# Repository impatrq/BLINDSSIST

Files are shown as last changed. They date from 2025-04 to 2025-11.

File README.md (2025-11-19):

<h1 align="center"><u>BLINDASSIST</u></h1>

<p align="center">
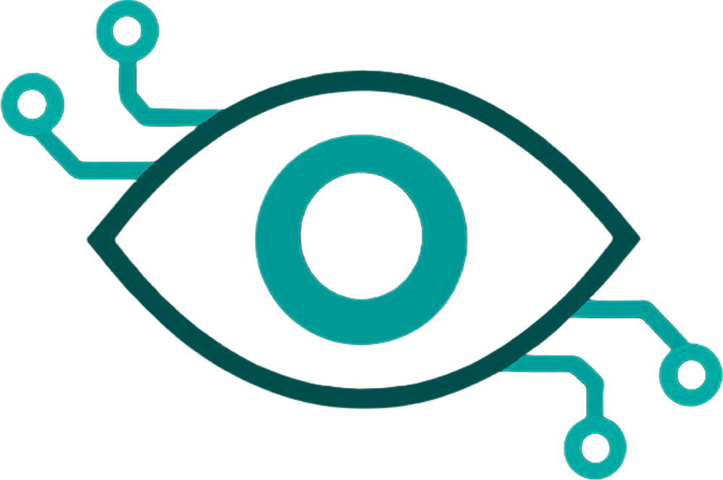
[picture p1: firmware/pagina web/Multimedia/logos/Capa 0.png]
BLINDSSIST Logo
  
</p>

<p align="center">

<!-- Video de Presentación -->
<a href="ACA_PONES_EL_LINK_DE_YOUTUBE_O_DRIVE" target="_blank">
  
</a>
<br>

<!-- Instagram -->
<a href="https://www.instagram.com/blindassist/" target="_blank">
  
</a>

<!-- LinkedIn -->
<a href="https://www.linkedin.com/in/proyecto-blindassist-72b0a7396" target="_blank">
  
</a>

<!-- Página Web -->
<a href="https://castiilloramiro.github.io/BlindWeb/" target="_blank">
  
</a>

<!-- Gmail -->
<a href="https://mail.google.com/mail/?view=cm&to=blindassist2025@gmail.com" target="_blank">
  
</a>

<!-- Linktree -->
<a href="http://linktr.ee/blindassist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" target="_blank">
  
</a>

</p>
## 🎯 Descripción  

BLINDASSIST es un proyecto orientado a facilitar el tránsito de usuarios con discapacidad visual en su vida cotidiana. A través de un dispositivo colgante —o integrado en algún accesorio— funciona como ayuda al bastón tradicional, ofreciendo:  

- 🔍 **Detección por cámara** de elementos específicos (por ejemplo: cestos de basura, señalizaciones, etc.).  

- 📡 **Sensores láser de proximidad** para obstáculos (ramas, postes, etc.).  

- 🔊 **Alertas sensoriales** (audio + vibración) para que el usuario pueda evitar los obstáculos.  

El dispositivo es portátil, compacto, fácil de llevar y diseñado para no interferir en las actividades diarias del usuario.

---

## 👥 Público objetivo  

- 👨‍🦯 Personas con discapacidad visual o movilidad reducida.  

- 🏥 Instituciones, aseguradoras o centros de rehabilitación que buscan tecnologías de apoyo.  

- 👨‍👩‍👧 Familiares o cuidadores que desean aumentar la seguridad en el tránsito.  

---

## 🛠️ Tecnologías

- **Hardware**: Sensores láser, cámara, actuadores de vibración
- **Firmware**: Código embebido para microcontroladores
- **Procesamiento**: Visión por computadora, detección de objetos
- **Frontend**: Interfaz web para configuración y monitoreo

---

## 📂 Estructura del repositorio  

```
BLINDSSIST/
├── Hardware/          # Diseño y esquemáticos del dispositivo
├── firmware/          # Código embebido y firmware
├── docs/              # Documentación del proyecto
```

---

## 🚀 Funcionalidades

| Característica | Descripción |
|---|---|
| 🎥 **Visión por IA** | Detección automática de elementos del entorno |
| 📏 **Sensores de Proximidad** | Detección de obstáculos en tiempo real |
| 🔊 **Feedback Auditivo** | Alertas de audio contextuales |
| 📳 **Feedback Háptico** | Vibraciones para notificaciones táctiles |
| 💻 **Interfaz Web** | Configuración y monitoreo del dispositivo |

---

## 🧑‍💻 Equipo 

<p align="center">
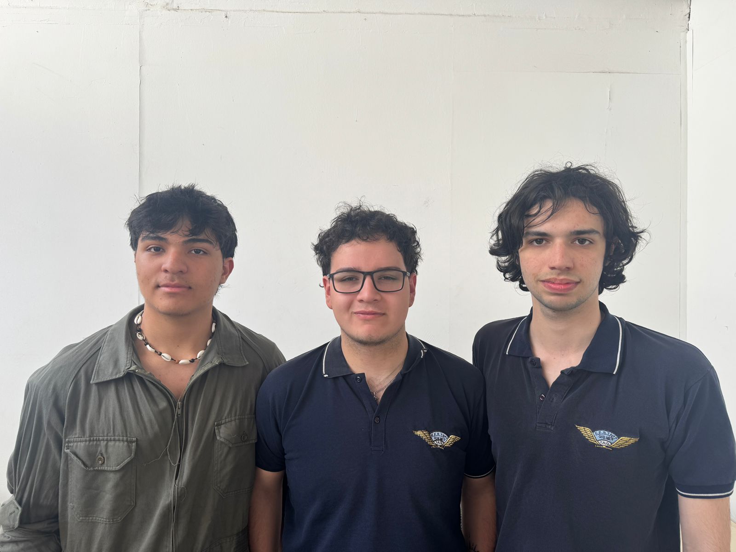
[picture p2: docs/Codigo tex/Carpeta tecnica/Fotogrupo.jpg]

</p>

### **Castillo Ramiro**
<a href="https://www.linkedin.com/in/ramiro-castillo-9a16b435b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" target="_blank">
  
</a>

<a href="https://mail.google.com/mail/?view=cm&to=castilloramiro06@gmail.com" target="_blank">
    

### **Pino Octavio**
<a href="https://www.linkedin.com/in/octavio-pino-b596b635b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" target="_blank">
  
</a>

<a href="https://mail.google.com/mail/?view=cm&to=octypino18@gmail.com" target="_blank">
    

### **Quattrocchi Tiago**
<a href="https://www.linkedin.com/in/tiago-quattrocchi-9146b335b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" target="_blank">
  
</a>

<a href="https://mail.google.com/mail/?view=cm&to=octypino18@gmail.com" target="_blank">
    

## 💙 Sponsors

<p align="center">
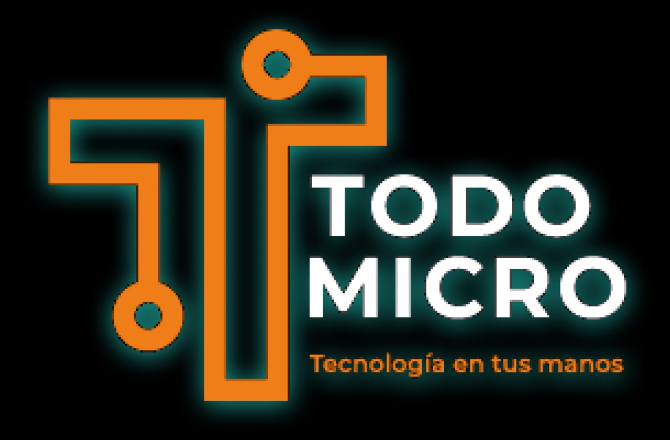
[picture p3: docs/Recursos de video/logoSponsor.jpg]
TODOMICRO Logo
  
</p>

Agradecemos profundamente a **TodoMicro** por su valioso apoyo y patrocinio de este proyecto. Su contribución nos permite continuar desarrollando tecnologías que mejoran la accesibilidad y la calidad de vida de las personas con discapacidad visual.

<a href="https://www.todomicro.com.ar/" target="_blank">
  
</a>
<a href="https://www.instagram.com/todomicrostore/?hl=es" target="_blank">
  
</a>

---

<p align="center">
  <b>Hecho con ❤️ para mejorar la accesibilidad</b>
</p>

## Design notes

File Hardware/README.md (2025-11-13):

# 🧩 Hardware

Esta Carpeta contiene todos los archivos relacionados con el **diseño físico y electrónico** del proyecto.  

## 📁 Contenido

- **PLACAS PCB** → Diseños de placas electrónicas (layout, gerbers, etc.)  
- **Conversor USB-TTL** → Hoja de datos.  
- **Diseños3D** → Modelos 3D de las carcasas, agarres y logos.
- **TFmini** → Hojas de datos.  
- **Fuente step-down** → Hojas de datos de los componentes utilizados.  

## 🛠️ Uso

Abrir cada subcarpeta según el área que necesites:
-  Revisar **esquemáticos** para entender las conexiones eléctricas.  Usar los archivos de **PCB** para fabricación o simulación.  
- Consultar **diseños 3D** para impresión o ensamblaje.  
- Ver los **datasheets** para obtener especificaciones técnicas de cada componente.

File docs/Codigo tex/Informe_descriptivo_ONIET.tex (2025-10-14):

\documentclass[12pt,a4paper]{article}
\usepackage[spanish]{babel}
\usepackage[utf8]{inputenc}
\usepackage{hyperref}
\usepackage{float}
\usepackage{geometry}
\usepackage{xcolor}
\usepackage{array}
\usepackage{longtable}
\usepackage{chngcntr}
\counterwithin{figure}{section}
\counterwithin{table}{section}
\usepackage{graphicx}
\usepackage{fancyhdr}
\usepackage{adjustbox}

\geometry{margin=2.5cm}

% Definimos el color de los meses y líneas
\definecolor{mescolor}{HTML}{024d50}
\definecolor{linecolor}{HTML}{024d50}
\definecolor{verdeagua}{HTML}{1B9E96}
\definecolor{verdeoscuro}{HTML}{002C2D}
\definecolor{verdemedio}{HTML}{004F4E}

% Cambiar color de secciones
\usepackage{titlesec}
\titleformat{\section}
{\color{mescolor}\normalfont\Large\bfseries}
{}{0pt}{}
\titlespacing*{\section}{0pt}{*2}{*1}

% Línea negra debajo de cada mes
\newcommand{\separador}{\vspace{0.5cm}\noindent\rule{\linewidth}{0.5pt}\vspace{0.5cm}}

% Cambiar color en el índice y tamaño más grande
\usepackage{tocloft}
\renewcommand{\cftsecfont}{\color{mescolor}\bfseries\Large}
\renewcommand{\cftsecpagefont}{\color{mescolor}\bfseries\Large}

% Configuración encabezado y pie de página con líneas de color y largo ajustable
\pagestyle{fancy}
\fancyhf{}
\fancyhead[L]{\textbf{Proyecto BlindAssist}}
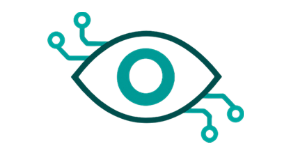
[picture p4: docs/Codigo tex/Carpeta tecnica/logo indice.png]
\fancyhead[R]{} % Espacio vacío para que no haya logo
\fancyfoot[C]{\thepage}

% Línea de encabezado de color y largo personalizado
\renewcommand{\headrulewidth}{0.4pt}
\renewcommand{\footrulewidth}{0.4pt}

\renewcommand{\headrule}{%
\color{linecolor}\hrule width 1\linewidth height 0.4pt \vskip0pt}
\renewcommand{\footrule}{%
\color{linecolor}\hrule width \linewidth height 0.4pt \vskip0pt}

\begin{document}

\begin{titlepage}
    \begin{center}
    
    % --- Imagen centrada en la parte superior ---
    \vspace*{2cm}
    \\[2cm] % <-- cambia la ruta a tu imagen

    % --- Título principal ---
    {\Huge\bfseries Proyecto BlindAssist \\[0.5cm]}
    {\Large Informe Descriptivo}\\[1.5cm]

    % --- Institución o facultad ---
    {\large Escuela de Educación Secundaria Tecnica N°7 "Taller Regional "}\\
    {\large 7°2 Avionica}

    % --- Espacio para dejar limpio el resto de la hoja ---
    \vfill
    \end{center}
\end{titlepage}

% Índice con numeración desde aquí
\setcounter{page}{1}
\setcounter{tocdepth}{4} % muestra hasta paragraph en el índice
\setcounter{secnumdepth}{4}
\tableofcontents
\newpage

%--- Introducción ---
\section{Introducción}

\subsection{Integrantes}
\begin{figure}[H]
    \centering
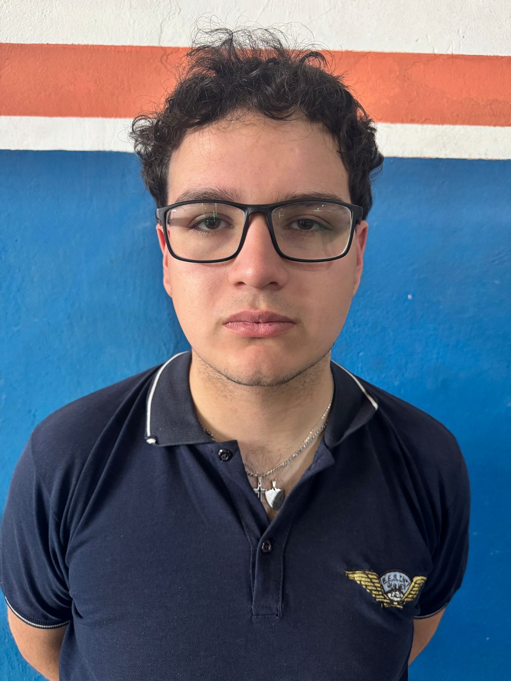
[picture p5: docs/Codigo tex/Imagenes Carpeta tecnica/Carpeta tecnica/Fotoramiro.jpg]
    
\end{figure}
\begin{center}
Castillo Ramiro\\
DNI: 47516171\\
7°2 Avionica
\end{center}

\begin{figure}[H]
    \centering
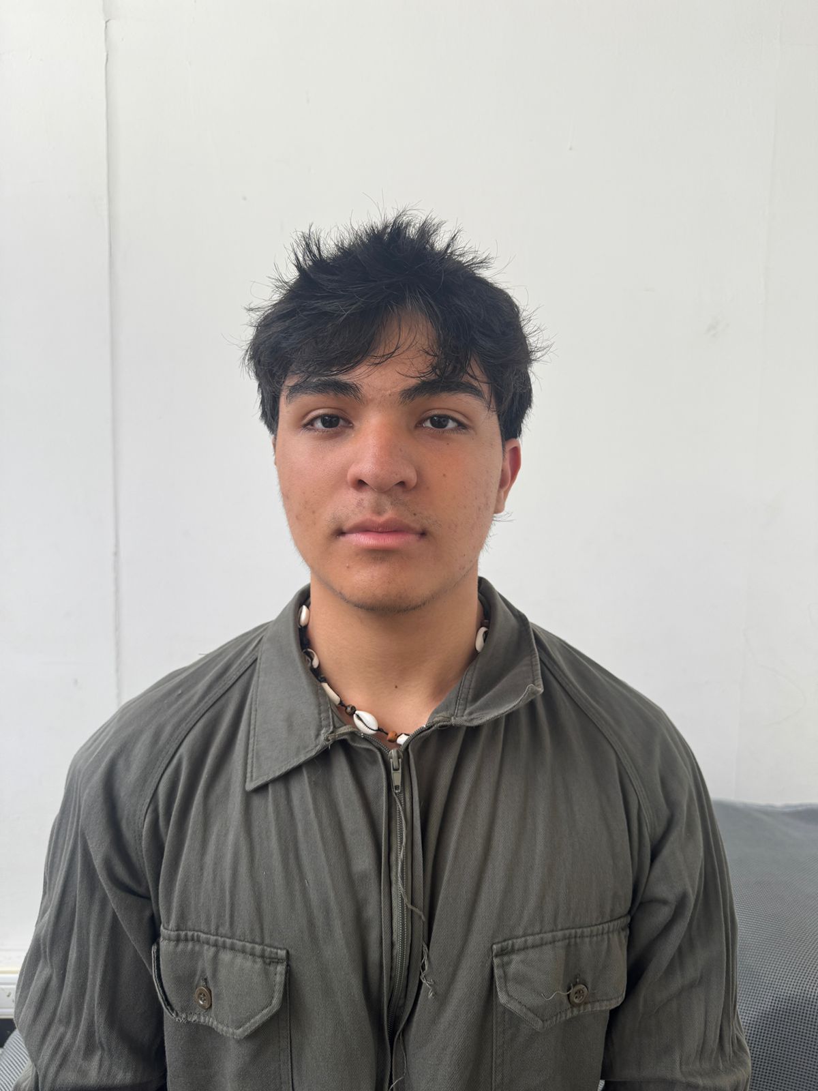
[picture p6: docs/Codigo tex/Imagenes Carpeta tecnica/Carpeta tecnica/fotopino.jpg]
    
\end{figure}
\begin{center}

Pino Octavio\\
DNI: 47882634\\
7°2 Avionica
\end{center}

\begin{figure}[H]
    \centering
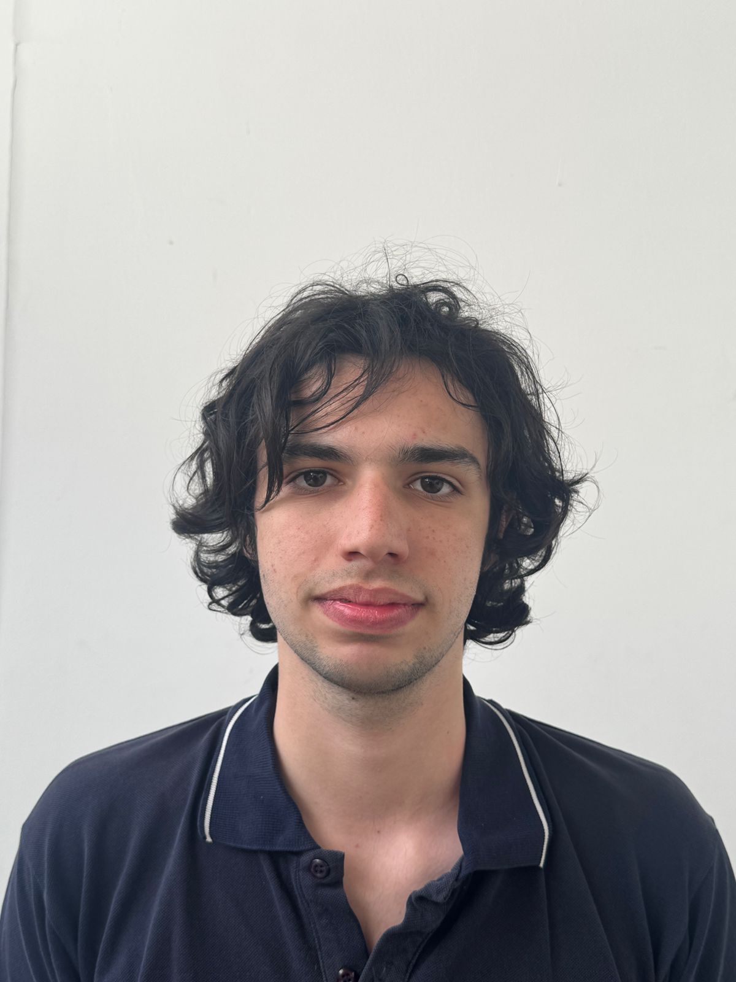
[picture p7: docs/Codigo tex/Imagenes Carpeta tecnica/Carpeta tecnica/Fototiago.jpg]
    
\end{figure}

\begin{center}
Quattrocchi Tiago\\
DNI: 47510542\\
7°2 Avionica
\end{center}

\begin{figure}[H]
    \centering
    
    \caption{Grupo BlindAssist}
\end{figure}

\subsection{Docentes a Cargo}
    \begin{center}
        \begin{itemize}
        \item Argüello Gabriel
        \item Bianco Carlos
        \item Carlassara Fabrizio
        \item Medina Sergio
        \item Palmieri Diego
        \end{itemize}
    \end{center}

\subsection{Desarrollo del proyecto}
\subsubsection*{Fecha de Inicio}
14/4/2025
\subsubsection*{Duración del proyecto}
25 Semanas
\subsubsection*{Esfuerzo del proyecto}
Maximo de 8 horas de trabajo (200 horas de trabajo en todo el año)
\subsubsection*{Lenguajes utilizados}
\begin{itemize}
\item LaTex
\item CSS
\item HTML
\item Python
\item Javascript
\end{itemize}

\subsubsection*{Programas utilizados}

\begin{itemize}
    \item OverLeaf
    \item Visual Studio Code
    \item Github Desktop
    \item Termius
    \item Proteus 8
    \item AutoCad
    \item UltiMaker
    \item Benewake Software
\end{itemize}

\separador

\section{Descripción}

\subsection{Objetivo}
El objetivo de este proyecto es mantener la integridad de las personas ciegas o con algún tipo de discapacidad visual en cualquier tipo de entorno urbano y darles un mayor nivel de conciencia en entornos mas cerrados. Para ello, desarrollamos un dispositivo que mediante reconocimiento por inteligencia artificial y la detección de objetos utilizando tecnología láser para avisar al usuario sobre un obstáculo en frente, por encima de la cadera, la presencia de alguna persona en un espacio cerrado y la cantidad de individuos que se encuentran en el mismo espacio, contando con alertas sonoras y vibratorias que no alteren su percepción y condición actual.Este dispositivo funcionara como una ayuda al bastón que utilizan en su día a día sin modificar su efectividad o tratar de reemplazar su función.

\subsection{Alcance}
\begin{itemize}

\item Cómo objetivo final, querríamos que este este proyecto llegue a ser un prototipo funcional y autónomo, con el menor tamaño posible para la comodidad del usuario. Contar con una IA correctamente entrenada y optimizada en rendimiento, que trabaje en conjunto al área cubierta y sensada por los lasers. Teniendo en cuenta las posibilidades, buscamos que las alertas sensoriales sean claras para el usuario así tiene una experiencia placentera en su día a día.
\end{itemize}

\subsection{Temática}

 \begin{itemize}
 \item Inclusión social: Nuestro proyecto abarca los parámetros presentados en la temática de inclusión social. Esto debido a que el proyecto mismo busca ayudar con el tránsito de las personas con discapacidad tanto en la vía pública cómo lugares cerrados desconocidos. Además, también puede ayudar con su comunicación y vida social, ya que los alerta de las personas que tienen a su alrededor. 
 \end{itemize}
 
\subsection{Problemas a resolver}

\begin{itemize}
\item Obstáculos repentinos en la vía publica, pueden presentar dificultad a la hora de detectar postes, árboles y otros peligros inesperados que se encuentren por encima de su tren inferior (a partir de la cadera), siendo que la mayoría de las veces el rango que cubre el bastón no es suficiente para detectar y avisar efectivamente a la persona con discapacidad visual.
\item El riesgo constante que sufren en la vía publica termina llevando a que dependan mucho de terceros, como puede ser transeúntes que los apoyen o en casos de personas con una edad mas avanzada, un cuidador designado o familiar cercano. Tenemos en cuenta la falta de autonomía que genera esta problemática, la dependencia que terminan teniendo de terceros es una de las problemáticas más importantes a resolver y la idea es darles una herramienta de autonomía e integración.
\item Proteger su intimidad pudiendo detectar personas que están en el mismo espacio cerrado sin depender de que la persona avise de su llegada, también permitiéndoles conocer la ubicación de dichos individuos, dándole un mejor sentido y conciencia situacional.
\end{itemize}

\subsection{Público beneficiado}
El proyecto está destinado a personas con impedimentos visuales. En el mundo hay 2200 millones de personas con visibilidad reducida, 43,3 millones son no videntes. Esta es la demográfica que será beneficiada directamente por el proyecto, habilitando el tránsito por la vía pública de manera más segura y sin problemas que puedan llegar a afectar su integridad o la rehabilitación a la que están sometidos. Además, al ser un accesorio portable, compacto y difícil de perder u olvidar, no interrumpe en las acciones que pueda realizar el usuario en su vida cotidiana. Este proyecto también beneficiará indirectamente a instituciones privadas como seguros de salud y ART (Aseguradoras de Riesgo del Trabajo), ya que estos pueden ofrecerle como una ayuda al grupo de personas antes descritas. También aplica para la vida cotidiana o la vida pública, ya que se reduce el riesgo de accidentes y la carga que supone a los familiares a la hora de ayudarlo.

\begin{figure}[H]
    \centering
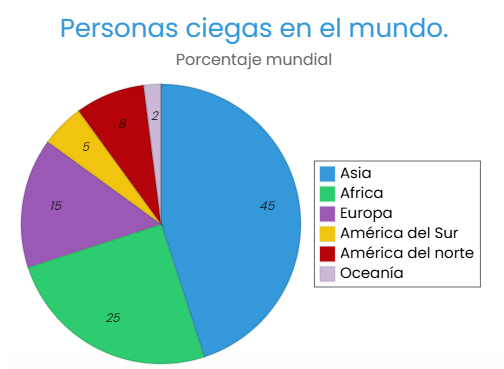
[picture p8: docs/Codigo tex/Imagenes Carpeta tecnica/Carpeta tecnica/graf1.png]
    
    \caption{Tabla de población ciega por continentes.}
\end{figure}

\subsection{Impacto}
 \begin{itemize}
 
\item En un contexto social, este prototipo tiene el potencial de transformar la vida de millones de personas. Como mencionamos anteriormente, más de 40 millones de personas en todo el mundo viven con discapacidad visual. Este impacto no solo afectaría a las personas con esta discapacidad, sino también a sus cuidadores y familiares directos. Es decir, podría beneficiar a una gran cantidad de personas y comunidades. Especialmente en regiones como África, Asia y América del Sur, donde existe un alto número de personas con discapacidad visual, pero donde los recursos y la infraestructura necesarios para facilitar su movilidad y vida cotidiana son limitados.

 \end{itemize}

\subsection{Descripción General}

\begin{itemize}

    \item BlindAssist es un proyecto que busca facilitar el tránsito de sus usuarios en la vida cotidiana. A través de un dispositivo colgante que puedan llevar encima mismos o en algún accesorio que mejore su movilidad. Esto lo lograríamos con un conjunto de componentes que trabajan en coordinación. Primero una cámara que detecta elementos específicos, por poner un ejemplo: cestos de basura, señalizaciones, etc. Segundo, unos sensores láser que detectan la proximidad de obstáculos cómo ramas u postes. Cómo tercero, alertas sensoriales a través de audio y vibraciones para alertar al usuario y que este pueda evitar estos inconvenientes.
    
\end{itemize}

\subsection{Funcionalidades}
\begin{itemize}
    \item El dispositivo presenta dos etapas de detección y dos de alerta al usuario. 
    El dispositivo realizará mediciones de distancia mediante los sensores TFmini LIDAR, estos se encuentran dispuestos de tal forma que puedan cubrir varios ángulos en frente de la persona. Acorde a la detección de los sensores, se le comunica al usuario la posición de un objeto intruso en el rango frontal, dependiendo que sensores detectan un objeto a menor distancia que 120cm se realizara un control de potencia de los motores internos, hay dos motores de vibración, uno a la izquierda y derecha del dispositivo, cada uno acorde a los sensores LIDAR de ambos lados, Cuando se detecta algo en el tercer TFmini cambia la organización, ambos motores emitirán la misma potencia, en caso de que el motor frontal y lateral detecten algo dicho lado tendrá un control titilante de la vibración, en caso de que los tres sensores se activen, ambos motores vibran al máximo de potencia.\\
    El sistema de detección basado en Inteligencia Artificial (IA), utiliza la cámara para capturar imágenes continuamente. Un modelo de IA avanzado (YOLOv8) actúa como el cerebro, escaneando cada imagen a alta velocidad para identificar y clasificar objetos relevantes para la seguridad, como personas, autos, bicicletas, camiones y objetos de tropiezo (botellas, etc.). Solo se anuncia un objeto si la IA está lo suficientemente segura de su clasificación (más del 60\% de confianza).
    La comunicación se realiza mediante voz asíncrona. Esta es la clave de la velocidad: el mensaje de voz (``Una persona", "3 autos", "Moto fuera") se envía a un proceso en segundo plano, permitiendo que la cámara y la IA sigan escaneando el entorno sin detenerse ni un instante. Para evitar el ruido constante, un filtro de tiempo de espera (cooldown) asegura que solo se anuncien los cambios de estado (algo nuevo apareció, se fue o cambió de cantidad) y no se repita la misma alerta cada pocos segundos.
    
\end{itemize}

\separador

\section{Hardware}

\subsection{Raspberry Pi 4}
La Raspberry Pi 4 es una computadora de placa única (SBC) compacta y de bajo consumo. A diferencia de las computadoras de escritorio tradicionales, está diseñada para tareas especializadas y prototipado. Utiliza un procesador Broadcom BCM2711 de cuatro núcleos y una arquitectura ARM, lo que la hace ideal para aplicaciones de robótica y automatización. Su funcionamiento se basa en la ejecución de un sistema operativo, como Raspberry Pi OS, que permite programar y controlar los componentes conectados a sus pines de GPIO (General Purpose Input/Output).
\begin{figure}[H]
\centering
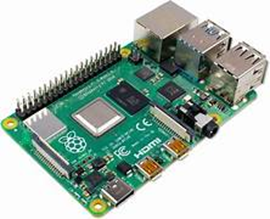
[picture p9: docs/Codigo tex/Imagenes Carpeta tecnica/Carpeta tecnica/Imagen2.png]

\caption{Modulo Raspberry PI 4}
\end{figure}

\subsubsection{PWM}

El PWM (Pulse Width Modulation) en la Raspberry Pi 4 es una técnica digital para generar señales moduladas en ancho de pulso que permiten controlar la potencia aplicada a dispositivos electrónicos.
En este modelo de placa, el PWM puede implementarse tanto por hardware (pines GPIO dedicados) como por software (emulación mediante librerías como RPi.GPIO o pigpio). En este proyecto se aplica para el control de los motores que funcionan como una alerta vibratoria.

\paragraph{Funcionamiento}
El PWM consiste en la generación de una onda cuadrada con dos parámetros principales:

\begin{itemize}
\item Frecuencia (f): cantidad de ciclos por segundo (Hz).

\item Duty cycle (\%): proporción del tiempo en que la señal está en estado alto respecto del periodo total.

La potencia media entregada a la carga es proporcional al duty cycle.
\end{itemize}

\subsubsection{UART}

El UART (Universal Asynchronous Receiver-Transmitter) es un protocolo de comunicación serie asíncrono que transmite y recibe datos bit a bit mediante dos líneas:

\begin{itemize}
    
\item TX (Transmit): envía datos.

\item RX (Receive): recibe datos.

\end{itemize}

\subsection{Raspberry PI CAM V1.3}

\begin{figure}[H]
    \centering
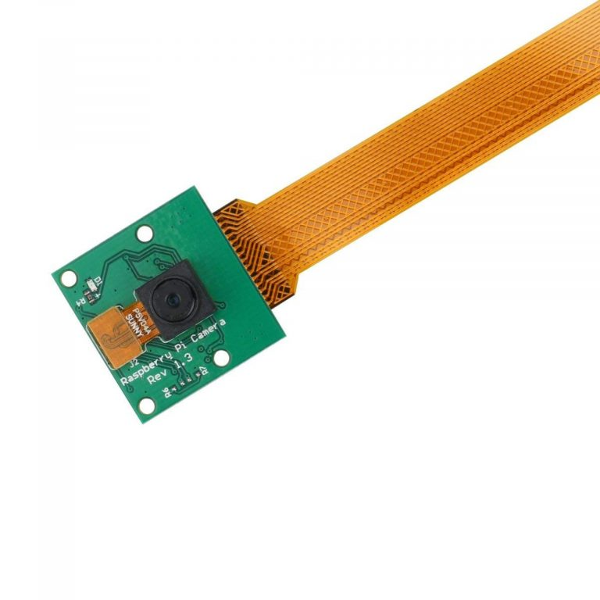
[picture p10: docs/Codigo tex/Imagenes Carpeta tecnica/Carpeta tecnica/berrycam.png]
    
    \caption{Raspberry PI CAM V1.3}
\end{figure}

La Raspberry Pi Camera Module v1.3 es una cámara oficial diseñada para las placas Raspberry Pi, basada en el sensor OmniVision OV5647 de 5 megapíxeles. Permite capturar imágenes fijas de hasta 2592×1944 píxeles y grabar video en resoluciones de 1080p a 30 fps, 720p a 60 fps y 480p a 90 fps. Se conecta mediante un cable plano CSI (Camera Serial Interface), lo que asegura una transmisión de datos rápida y optimizada.

Este módulo es compacto y ligero, ideal para visión por computadora, robótica, monitoreo y aplicaciones de IoT. Gracias a su integración directa con la Raspberry Pi y la compatibilidad con librerías como Picamera y OpenCV.

\subsection{TFmini}
El TFmini es un sensor de distancia LiDAR (Light Detection and Ranging). Funciona emitiendo un pulso de láser infrarrojo y midiendo el tiempo que tarda la luz en rebotar en un objeto y regresar al sensor. Esta técnica, conocida como tiempo de vuelo (ToF), le permite calcular la distancia con precisión. Se comunica con la Raspberry Pi a través de interfaces como UART (puerto serie) o I2C, lo que le permite obtener lecturas de distancia de forma rápida y confiable.

\begin{figure}[H]
    \centering
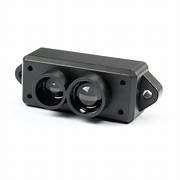
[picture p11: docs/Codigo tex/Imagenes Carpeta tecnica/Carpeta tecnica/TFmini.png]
    
    \caption{TFmini S}
\end{figure}

\subsubsection{Descripción General y Principio de Funcionamiento}

El TFmini es un mini módulo LiDAR diseñado para realizar funciones de medición de distancia sin contacto y en tiempo real. Se caracteriza por ofrecer una medición de distancia precisa, estable y de alta velocidad.

El sensor opera bajo el principio de TOF (Time of Flight). El módulo transmite periódicamente una onda de modulación de rayo infrarrojo cercano que se refleja al contactar un objeto. El producto calcula el rango relativo al objeto al medir la diferencia de fase de ida y vuelta (tiempo de vuelo) de la señal.

\begin{figure}[H]
    \centering
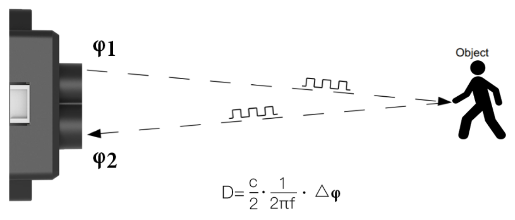
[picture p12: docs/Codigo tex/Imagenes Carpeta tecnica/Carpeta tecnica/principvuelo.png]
    
    \caption{Principio de tiempo de vuelo}
    \label{fig:placeholder}
\end{figure}

\subsection{Conversor TTL a USB}

El CP2102 es un controlador de puente USB a UART altamente integrado que permite la conversión directa entre interfaces USB y serie. Este dispositivo es ideal para actualizar sistemas que originalmente utilizaban comunicación RS-232, TTL o RS-485, eliminando la necesidad de puertos seriales tradicionales en PCs modernas.  
Gracias a su tamaño compacto y a la mínima cantidad de componentes externos necesarios, el CP2102 ofrece una solución eficiente, confiable y económica para la comunicación entre ordenadores y dispositivos embebidos.
En el caso de este proyecto se utilizara de forma que pueda comunicar la lectura de los tres LIDAR efectivamente teniendo en cuenta la cantidad de salidas USB disponibles por la placa, y que la Raspberry PI 4 presenta únicamente una salida serial por pines.

\begin{figure}[H]
\centering
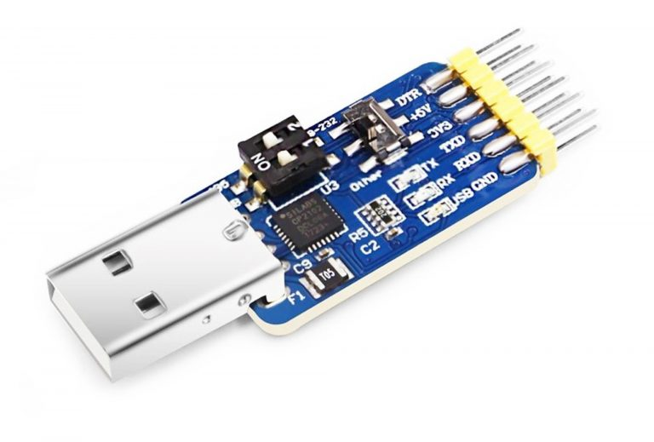
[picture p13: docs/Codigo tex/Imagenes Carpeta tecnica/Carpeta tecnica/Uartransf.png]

\caption{Conversor Serie TTL a USB}
\end{figure}

\subsubsection{Funcionamiento}
El CP2102 actúa como un puente entre la interfaz USB 2.0 y los protocolos UART, RS-232 o RS-485 del dispositivo conectado.  
El chip convierte los datos USB en señales serie y viceversa, facilitando la transmisión y recepción asíncrona de datos.  
El módulo no requiere componentes externos USB y es reconocido automáticamente por la mayoría de los sistemas operativos mediante drivers integrados.

\subsection{Circuito}

\subsubsection{Lista de Componentes}
\begin{longtable}{|>{\raggedright}p{4cm}|c|>{\raggedright\arraybackslash}p{8cm}|}
\hline
\textbf{Componente} & \textbf{Cantidad} & \textbf{Descripción / Función} \\
\hline
Raspberry Pi 4 (J5) & 1 & Microprocesador central, adquisición de datos y control \\
\hline
Sensor TFmini (J1, J2, J3) & 3 & LIDAR para medir distancias \\
\hline
Motores de vibración (J6, J7) & 2 & Generación de señal haptica de alerta \\
\hline
Transistor BC337 (Q1, Q2) & 2 & Etapa de potencia para buzzers \\
\hline
Resistencias 330 $\Omega$ (R1, R2) & 2 & Limitación de corriente en base de transistores \\
\hline
Interruptores (J4, J8) & 2 & Habilitación/deshabilitación manual \\
\hline
Alimentación de baterías (J9, J10) & 2 & Alimentación de la Raspberry Pi 4 y de los motores de vibración)\\
\hline
\caption{Tabla de la lista de componentes del circuito}
\end{longtable}

%--------------------------
\subsubsection{Descripción del circuito}
\begin{enumerate}
    \item Los sensores TFmini (J1, J2, J3) envían datos de distancia vía UART a la Raspberry Pi 4 (J5), dejando como futura posibilidad la comunicacion de UART por software para J2 y J3, teniendo en cuenta que mediante pines unicamente se puede comunicar con J1.
    \item La Raspberry Pi recibe y procesa la información. Si la distancia medida es menor a un umbral, activa una salida GPIO.
    \item El GPIO activa Q1 o Q2 mediante las resistencias R1 y R2.
    \item Los transistores permiten el paso de corriente hacia los motores (J6, J7), que generan la alerta haptica de vibración.
    \item Los interruptores J4 y J8 permiten habilitar/deshabilitar la detección de la IA y seleccionar modos de funcionamiento.
\end{enumerate}

\subsubsection{Esquemático}

\begin{figure}[H]
    \centering
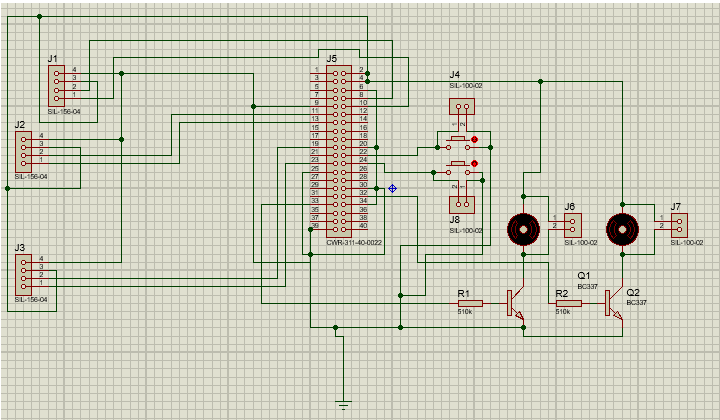
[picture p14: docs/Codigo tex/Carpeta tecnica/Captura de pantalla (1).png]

\caption{Esquemático del circuito final}
\end{figure}

\subsubsection{PCB}

\begin{figure}[H]
    \centering
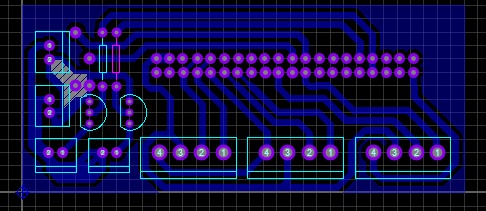
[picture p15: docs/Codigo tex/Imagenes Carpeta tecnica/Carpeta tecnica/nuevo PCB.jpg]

\caption{diseño de impresión del circuito}
\end{figure}

\separador

\section{Firmware} 

\subsection{Detección por IA}
El sistema de visión artificial implementado en este proyecto se basa en el modelo de aprendizaje profundo YOLOv8n.pt para la identificación de objetos en tiempo real, utilizando la cámara de la Raspberry Pi como fuente de datos. La arquitectura del software se estructura en un sistema de Programación Orientada a Objetos (POO). Cada componente lógico (cámara, IA, voz, traductor) está encapsulado en una clase dedicada, lo que facilita el desarrollo, las pruebas y el mantenimiento del sistema de manera modular.

\begin{figure}[H]
\noindent\hspace*{-0.7in}% desplaza hacia la izquierda el origen
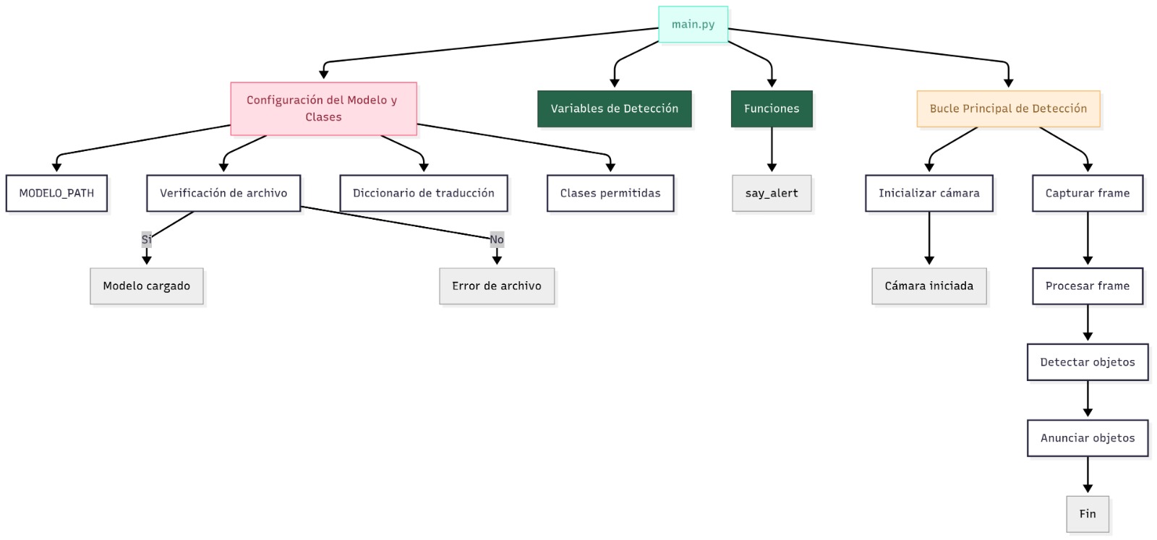
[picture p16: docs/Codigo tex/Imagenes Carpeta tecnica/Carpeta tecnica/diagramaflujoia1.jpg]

\caption{Diagrama de flujo de la detección por IA}
\end{figure}

\subsubsection{logica del bucle continuo}
\begin{itemize}
\item Captura frames de video.
\item Analiza cada frame en busca de objetos.
\item Compara las detecciones con las del frame anterior.
\item Emite una alerta de voz solo cuando se detecta un cambio en el entorno (aparición o desaparición de un objeto).
\end{itemize}

\subsubsection{Arquitectura del Código}
El programa se organiza en un conjunto de clases principales:
\begin{itemize}
\item \textbf{Clase Camara:} Gestiona el hardware de la cámara. Utiliza la librería picamera2 para inicializar y capturar un stream de video en vivo. A diferencia de soluciones de un solo fotograma, esta aproximación optimiza el rendimiento y la tasa de fotogramas por segundo (FPS) al mantener el stream de video abierto.
\item \textbf{Clase IA:} Carga el modelo yolov8n.pt y es responsable de analizar los fotogramas capturados. Identifica objetos en una lista predefinida de clases (clases\_permitidas) y filtra las detecciones por un umbral de confianza (CONFIDENCE\_THRESHOLD), asegurando que solo los objetos relevantes y con alta certeza sean considerados.
\item \textbf{Clase Traductor:} Encapsula el diccionario de traducciones. Su única responsabilidad es convertir los nombres de las clases de YOLO (en inglés, como 'person' o 'car') a sus equivalentes en español, permitiendo que el sistema de voz dé las alertas en el idioma del usuario.
\item \textbf{Clase Voz:} Maneja la síntesis de voz. Para garantizar la fiabilidad del audio, utiliza un método robusto basado en la librería subprocess para ejecutar el comando del sistema espeak y vocalizar las alertas. Esta solución es inmune a los problemas de configuración de audio que se presentan a menudo con otras librerías.
\item \textbf{Clase Main:} Es el punto principal del sistema. Inicializa todas las demás clases y gestiona el bucle de detección en tiempo real. Su lógica más avanzada reside en el método privado \_\_anunciar\_detecciones, que compara las detecciones actuales con las del último ciclo, emitiendo una alerta de voz únicamente cuando se detecta un cambio. Esto evita la repetición constante de las mismas alertas.
\end{itemize}
El sistema se ejecuta continuamente en un bucle while hasta que el usuario lo interrumpe con Ctrl + C. En ese momento, un bloque finally asegura que el hardware de la cámara se detenga de manera segura para evitar fallos del sistema.

\begin{figure}[H]
\noindent\hspace*{-0.7in}% desplaza hacia la izquierda el origen
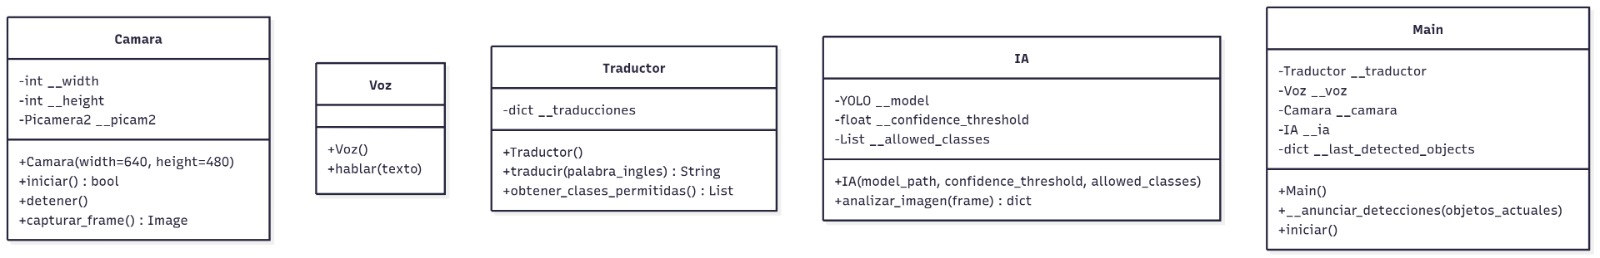
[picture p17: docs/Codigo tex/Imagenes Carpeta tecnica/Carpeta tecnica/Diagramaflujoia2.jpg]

\caption{Diagrama de flujo de clases}
\end{figure}

\subsubsection{Componentes de la Implementación}
\paragraph{Librerías}
\begin{itemize}
\item ultralytics: Se utiliza para cargar y ejecutar el modelo de detección de objetos YOLOv8.
\item picamera2: La interfaz oficial para las cámaras de la Raspberry Pi, proporcionando acceso a un flujo de video de alto rendimiento.
\item cv2 (OpenCV): Se usa para el preprocesamiento de los fotogramas, como la conversión de color necesaria antes de pasarlos al modelo de IA.
\item subprocess: La herramienta estándar de Python para ejecutar comandos del sistema, en este caso, el motor de síntesis de voz espeak.
\item os y sys: Permiten la gestión de archivos y el control del sistema, por ejemplo, para verificar la existencia del modelo YOLO antes de su uso.
\end{itemize}

\paragraph{Manejo de Flujo de Datos}
El flujo de información y la lógica de control se manejan principalmente en el método iniciar() de la clase Main:
\begin{itemize}
\item \textbf{Captura:} self.\_\_camara.capturar\_frame() obtiene una imagen del stream de la cámara.
\item \textbf{Análisis:} El frame se pasa a self.\_\_ia.analizar\_imagen(frame), que devuelve un diccionario con los objetos detectados en el fotograma actual.
\item \textbf{Control de Anuncios:} El diccionario se envía al método \_\_anunciar\_detecciones().
\item \textbf{Reproducción de Audio:} Si hay cambios, la clase Voz es invocada a través de self.\_\_voz.hablar(final\_message).
\end{itemize}
La arquitectura del sistema es muy escalable. Al estar modularizado, se podrían añadir fácilmente nuevas clases sin modificar la lógica central del proyecto.

\subsection{Detección por láser}
\subsubsection{Libreria TFmini}
Esta sección describe el funcionamiento del código implementado para la lectura simultánea de tres sensores LiDAR TFmini conectados a diferentes puertos UART de una Raspberry Pi 4.

El sistema permite:
\begin{itemize}
\item Recepción continua de datos desde los sensores.
\item Procesamiento y almacenamiento de las distancias medidas.
\item Ejecución en paralelo mediante hilos (multithreading).
\item Disponibilidad centralizada de los valores para otras funciones del sistema.
\end{itemize}

\textbf{Descripción General del Sistema:}
El programa se estructura en cuatro bloques principales:
\begin{itemize}
\item Configuración global: Definición de librerías, estructuras de datos y variables compartidas.
\item Módulo de adquisición de datos: Funciones de lectura desde los sensores a través de los puertos UART.
\item Gestión de hilos: Creación de procesos concurrentes para la lectura simultánea.
\item Bucle principal: Supervisión e impresión periódica de los valores capturados.
\end{itemize}
La arquitectura se basa en la comunicación serial estándar (UART) a una velocidad de 115200 baudios, con tramas de 9 bytes emitidas por cada TFmini.

\paragraph{Librerías:}
\begin{itemize}
\item \textbf{serial (pyserial):} Permite abrir, configurar y gestionar la comunicación UART.
\item \textbf{time:} Se utiliza para pausas entre lecturas y evitar sobrecarga del procesador.
\item \textbf{threading:} Facilita la ejecución concurrente de múltiples lecturas de sensores.
\end{itemize}

\paragraph{Estructuras Globales:}
\begin{verbatim}
distancias = {
"uart1": None,
"uart2": None,
"uart3": None,
}
\end{verbatim}
Diccionario que almacena la última distancia válida obtenida de cada sensor. Inicialmente los valores son None y se actualizan en tiempo real. Facilita la consulta de datos desde cualquier parte del programa.

\paragraph{Función Genérica de Adquisición de Datos:}

\begin{verbatim}
def getTFminiData(port, key_name):
ser = serial.Serial(port, 115200, timeout=1)
\end{verbatim}

\textbf{Flujo de la función:} 
Apertura del puerto serie con parámetros: Velocidad de 115200 baudios, timeout de 1 segundo. Bucle infinito de lectura: Verifica si hay al menos 9 bytes disponibles (ser.in\_waiting > 8). Lee un paquete completo (ser.read(9)). Validación de cabecera: Primeros dos bytes deben ser 0x59 0x59. Si no coincide, se descarta la trama. Reconstrucción de la distancia: Byte [2] = parte baja (Low). Byte [3] = parte alta (High). Cálculo: distance = low + (high << 8).

\end{quoting}

\paragraph{Almacenamiento de datos}
La distancia calculada se guarda en el diccionario global bajo la clave correspondiente (uart1, uart2, uart3). Retardo de control time.sleep(0.01) para liberar recursos del procesador.

\paragraph{Funciones Específicas por Puerto UART}

\begin{verbatim}
def getTFminiData_uart1():
getTFminiData("/dev/serial0", "uart1")
\end{verbatim}
Función getTFminiData\_uart1: Llama al puerto /dev/serial0. Función getTFminiData\_uart2: Llama al puerto /dev/ttyUSB1. Función getTFminiData\_uart3: Llama al puerto /dev/ttyUSB2. Estas funciones permiten escalar el sistema sin modificar la lógica principal.

\paragraph{Gestión de Hilos y Ejecución Principal}
\begin{verbatim}
if __name__ == '__main__':
...
\end{verbatim}
Creación de hilos: Cada hilo ejecuta una de las funciones específicas (uart1, uart2, uart3). Se utilizan hilos daemon, lo que asegura que se cierren cuando termine el programa. Ejecución concurrente: Los tres hilos inician en paralelo con .start(). Se garantiza la lectura simultánea de los sensores. Bucle principal de supervisión: Cada segundo imprime las distancias almacenadas en distancias y permite monitorear en consola el funcionamiento del sistema. Interrupción del usuario: Al presionar Ctrl + C, se captura la excepción KeyboardInterrupt. Se muestra un mensaje de salida segura.

\begin{figure}[H]
\noindent\hspace*{-0.7in}% desplaza hacia la izquierda el origen
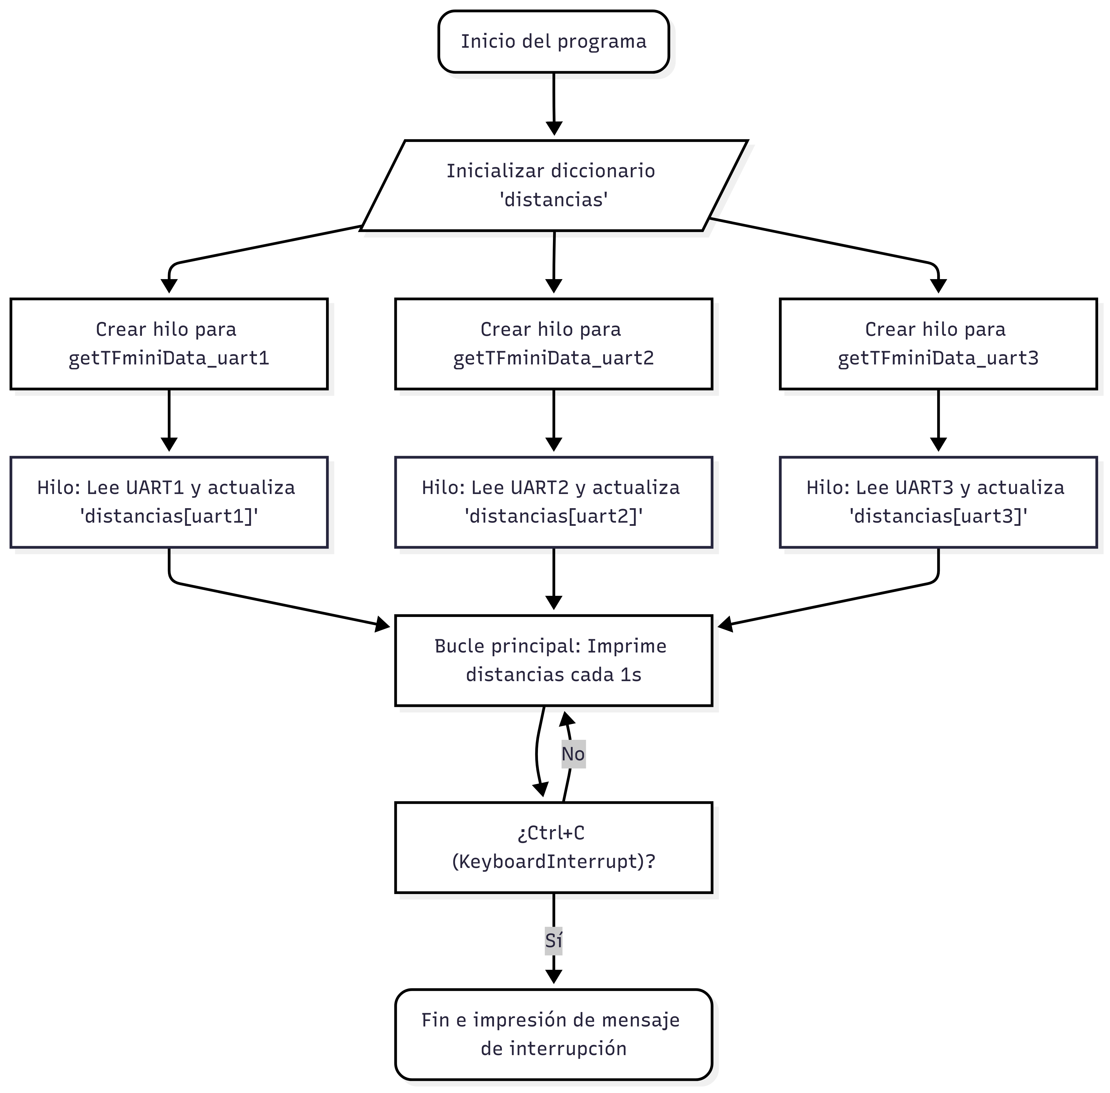
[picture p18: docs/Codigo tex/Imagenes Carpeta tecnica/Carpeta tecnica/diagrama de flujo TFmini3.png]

\caption{Diagrama de flujo de la lectura de distancias}
\end{figure}

\subsubsection{Control de Motores}

El código implementa un sistema de control de dos motores mediante modulación por ancho de pulso (PWM) utilizando una Raspberry Pi 4.  
El control se basa en las distancias medidas por tres sensores LiDAR TFmini conectados a los puertos UART de la Raspberry Pi.  
El objetivo del programa es variar la velocidad de los motores en función de la proximidad de obstáculos, generando alertas hapticas (mediante vibraciones) cuando se detectan objetos a menos de 120 cm.

\paragraph{Librerías y Dependencias}

\begin{itemize}
    \item \texttt{time}: Control de tiempos y retardos.
    \item \texttt{threading}: Permite ejecutar lecturas de los tres sensores en paralelo mediante hilos.
    \item \texttt{RPi.GPIO}: Control de los pines GPIO de la Raspberry Pi.
    \item \texttt{TFtest3}: Módulo externo que contiene las funciones de lectura \texttt{getTFminiData\_uart1/2/3} y el diccionario \texttt{distancias}.
\end{itemize}

\paragraph{Configuración del Sistema}

\begin{itemize}
    \item\textbf{Modo GPIO:}

\begin{verbatim}
GPIO.setmode(GPIO.BCM)
\end{verbatim}

\item\textbf{Asignación de Pines PWM:}
\begin{verbatim}
MOTOR_PIN1 = 18
MOTOR_PIN2 = 13
\end{verbatim}

Estos pines son compatibles con PWM por hardware en la Raspberry Pi 4.

\item\textbf{Inicialización de PWM:}
\begin{verbatim}
pwm1 = GPIO.PWM(MOTOR_PIN1, 100)
pwm2 = GPIO.PWM(MOTOR_PIN2, 100)
pwm1.start(0)
pwm2.start(0)
\end{verbatim}

Se inicializan ambas salidas con una frecuencia de \textbf{100 Hz} y un duty cicle del \textbf{0 \%}.
\end{itemize}

\paragraph{Función Auxiliar}
\begin{itemize}
\texttt{calcular\_duty(d):} Esta función traduce la distancia medida (en cm) al porcentaje de ciclo útil del PWM.  
Si el objeto está a menos de \textbf{120 cm}, el duty cycle aumenta proporcionalmente al acercamiento.

\begin{verbatim}
if d < 120:
    return min(100, 120 - d)
\end{verbatim}

Ejemplo de funcionamiento:
\begin{itemize}
    \item Si $d = 100$ cm $\rightarrow$ $duty = 20\%$
    \item Si $d = 50$ cm $\rightarrow$ $duty = 70\%$
\end{itemize}
\end{itemize}

\paragraph{Lógica de Control Principal}
\begin{itemize}

Función central que coordina la lectura de los tres sensores y actualiza los dos motores según las condiciones detectadas.

\textbf{Ciclo de operación:}

\begin{enumerate}
    \item Reinicia el PWM en 0\% al comienzo de cada ciclo.  
    \item Lee las distancias \texttt{d1}, \texttt{d2}, \texttt{d3} desde el diccionario compartido \texttt{distancias}.  
    \item Calcula los valores de duty correspondientes.  
    \item Evalúa las condiciones de proximidad menores a 120 cm.  
\end{enumerate}

\textbf{Casos contemplados:}

\begin{table}[H]
\centering
\begin{tabular}{|c|p{5cm}|p{7cm}|}
\hline
\textbf{Caso} & \textbf{Condición} & \textbf{Acción} \\ \hline
1 & d1 $<$ 120 & Activa PWM1 proporcionalmente. \\ \hline
2 & d2 $<$ 120 & Activa PWM2 proporcionalmente. \\ \hline
3 & d3 $<$ 120 & Ambos motores actúan con el mismo PWM. \\ \hline
4 & d2 y d3 $<$ 120 & Motor 2 titila alternadamente. \\ \hline
5 & d1 y d3 $<$ 120 & Motor 1 titila alternadamente. \\ \hline
6 & d1, d2 y d3 $<$ 120 & Ambos motores al 100\% (alerta crítica). \\ \hline
\end{tabular}
\caption{Casos de control de motores según distancias detectadas.}
\end{table}
\end{itemize}

\begin{figure}[H]
    \centering
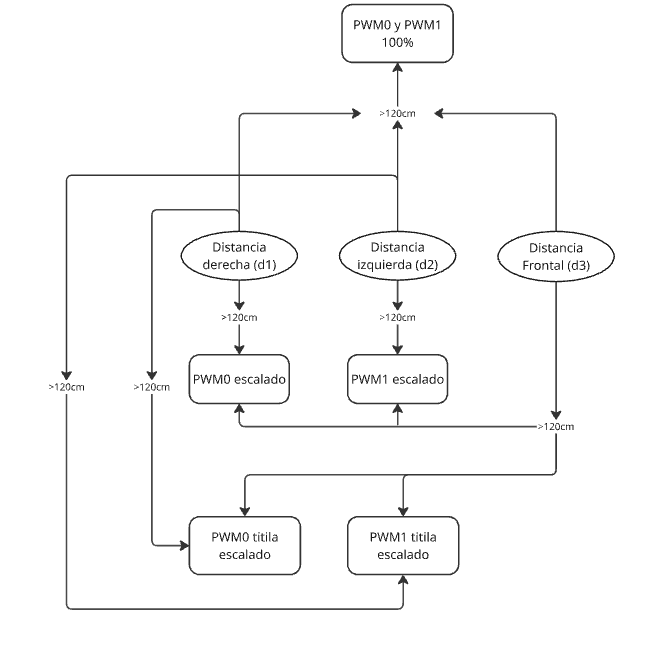
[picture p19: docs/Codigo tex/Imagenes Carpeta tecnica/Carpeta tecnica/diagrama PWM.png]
    
    \caption{Diagrama de flujo de la lógica PWM}
\end{figure}

\separador

\section{Diseño}

\subsection*{ Prototipo 3D}

\subsection*{ Materiales Utilizados / Programas}
\begin{itemize}
\item Filamento de impresión 3D PLA.
\item Tornillos 1/8
\item AutoCAD
\end{itemize}

\subsection{Diseño General}
El diseño corresponde a un prototipo de carcasa destinado a integrar de forma eficiente los sensores y componentes del proyecto. Su geometría incluye un frente inclinado en forma triangular, que permite optimizar los ángulos de medición de los LIDAR y ampliar su campo de detección en entornos urbanos. También incorpora un orificio frontal para la cámara y tres ranuras específicas para los LIDAR, lo que asegura una orientación precisa y funcional. El sistema de cierre se resuelve mediante anclajes en el borde del cuerpo y orejas externas para tornillos, lo que garantiza un ajuste firme y facilita el mantenimiento. A nivel general, el prototipo busca maximizar el aprovechamiento del espacio interno, mejorar la disposición de los sensores y proteger los componentes electrónicos. Es importante remarcar que se trata de un prototipo en evolución, sujeto a mejoras tanto en la disposición interna como en la ergonomía y robustez del ensamble.

\subsection{Comparaciones entre Versiones}
\begin{itemize}
\item \textbf{Espacio interno:} El primer prototipo no contaba con el espacio suficiente para albergar todos los componentes electrónicos. En el segundo, se corrigieron dimensiones y proporciones, logrando una organización más adecuada del volumen interno.
\item \textbf{Ranuras para sensores LIDAR:} En el primer modelo, las ranuras eran más genéricas y no contemplaban bien la orientación de los sensores. El segundo prototipo introdujo tres ranuras específicas para los LIDAR, con un frente inclinado que mejora el ángulo de detección.
\item \textbf{Relieves y fijaciones internas:} El primer y segundo prototipo carecían de soporte interno para los componentes. En el tercer prototipo, que exteriormente mantiene la misma geometría, se añadieron relieves interiores para que los LIDAR queden bien posicionados y se incorporaron finalmente los anclajes para fijar las plaquetas electrónicas, permitiendo un montaje más firme y seguro.
\item Sistema de cierre: Desde el segundo prototipo ya se contemplaban orejas externas para tornillería, pero en el prototipos siguiente se mejoró la definición de los encastres en el borde del cuerpo, logrando un cierre más sólido.
\item La serie de prototipos muestra una mejora constante en la funcionalidad y organización interna de la carcasa. El primer prototipo permitió validar dimensiones generales. El segundo resolvió la correcta orientación de los LIDAR con el frente inclinado y el aumento de espacio. El tercero introdujo finalmente los relieves interiores y fijaciones internas, mejorando la integración de los componentes. Este proceso iterativo confirma que el diseño está en el camino correcto, pero aún con margen para seguir perfeccionando aspectos de robustez estructural, ensamblaje y usabilidad.
\end{itemize}

\subsection{Imágenes}
\subsubsection{Primer Prototipo}
\begin{figure}[H]
    \centering
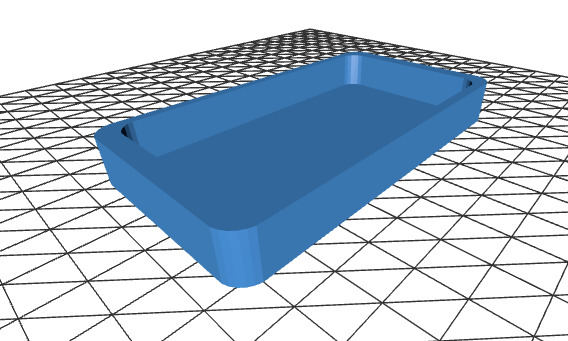
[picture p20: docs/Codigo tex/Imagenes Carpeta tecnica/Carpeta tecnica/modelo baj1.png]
    
    \caption{Primera base}
\end{figure}
\begin{figure}[H]
    \centering
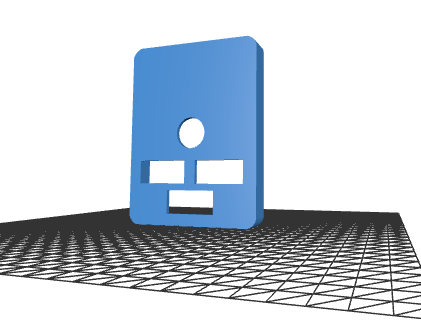
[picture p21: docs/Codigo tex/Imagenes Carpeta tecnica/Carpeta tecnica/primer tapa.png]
    
    \caption{Primera tapa}
\end{figure}

\subsubsection{Segundo Prototipo}

\begin{figure}[H]
    \centering
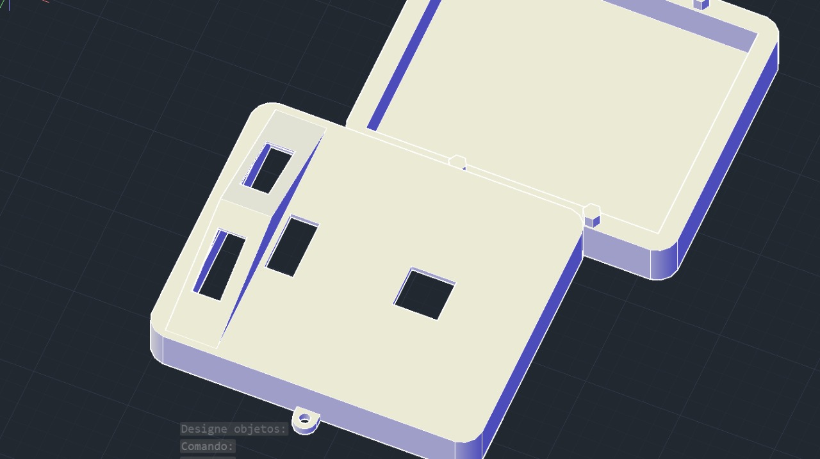
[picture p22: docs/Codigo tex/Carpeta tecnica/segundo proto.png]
    
    \caption{Tapa y base}
\end{figure}

\separador

\begin{thebibliography}{9}

\subsection{Datasheets y manuales}

\bibitem{raspberrypi4}
\emph{Raspberry pi 4 datasheet:}. \href{https://github.com/impatrq/BLINDSSIST/blob/main/Hardware/raspberry-pi-4-datasheet.pdf}{https://github.com/impatrq/BLINDSSIST/raspberry-pi-4-datasheet.pdf}

\bibitem{raspberry_cam}
Raspberry Pi Foundation. 
\emph{Raspberry Pi Camera Module v1.3 Documentation:}. \href{https://www.raspberrypi.com/documentation/accessories/camera.html}{https://www.raspberrypi.com/documentation/accessories/camera.html}

\bibitem{tfmini_doc}
Benewake. 
\emph{TFmini LiDAR Product Manual:} \href{https://github.com/impatrq/BLINDSSIST/blob/main/Hardware/TFmini/SJ-PM-TFmini-T-01_A06%20Product%20Manual_EN.pdf}{https://github.com/impatrq/BLINDSSIST/SJ-PM-TFmini-T-01_A06}

\bibitem{TFminidatasheet}
\emph{TFmini Lidar Datasheet:}
\href{https://github.com/impatrq/BLINDSSIST/blob/main/Hardware/TFmini/SJ-GU-TFmini-T-01_A05%20Datasheet.pdf}{https://github.com/impatrq/BLINDSSIST/SJ-GU-TFmini-T-01_A05}

\bibitem{convserieausb}
\emph{Conversor serie a usb datasheet:}
\href{https://www.alldatasheet.com/datasheet-pdf/pdf/201067/SILABS/CP2102.html}{https://www.alldatasheet.com/datasheet-pdf/pdf/201067/SILABS/CP2102.html}

\bibitem{fuente}
\emph{Conversor buck step-down datasheet:}
\href{https://www.alldatasheet.com/datasheet-pdf/pdf/1134361/XLSEMI/XL4015.html}{https://www.alldatasheet.com/datasheet-pdf/pdf/1134361/XLSEMI/XL4015.html}

\subsection{Software}

\bibitem{TFmini}
\emph{Lectura de sensor TFmini:}
\href{https://github.com/impatrq/BLINDSSIST/blob/main/firmware/TFmini3.py}{https://github.com/impatrq/BLINDSSIST/TFmini3.py}

\bibitem{ContPWM}
\emph{Control de motores:}
\href{https://github.com/impatrq/BLINDSSIST/blob/main/firmware/TFmini/ContPWM.py}{https://github.com/impatrq/BLINDSSIST/ContPWM.py}

\bibitem{Cam}
\emph{Codigo de deteccion de IA:}
\href{https://github.com/impatrq/BLINDSSIST/blob/main/firmware/main.py}{https://github.com/impatrq/BLINDSSIST/mainPOO.py}

\bibitem{POO}
\emph{Codigo de Python orientado a objetos: }
\href{https://github.com/impatrq/BLINDSSIST/blob/main/firmware/mainPOO.py}{https://github.com/impatrq/BLINDSSIST/mainPOO.py}

\subsection{Pagina web}
\bibitem{Página web}
\emph{Carpeta de Web BlindAssist}
\href{https://github.com/impatrq/BLINDSSIST/tree/main/firmware/pagina%20web}{https://github.com/impatrq/BLINDSSIST/pagina}
\end{thebibliography}

\end{document}

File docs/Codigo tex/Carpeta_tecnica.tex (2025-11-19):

\documentclass[12pt,a4paper]{article}
\usepackage[spanish]{babel}
\usepackage[utf8]{inputenc}
\usepackage{hyperref}
\usepackage{float}
\usepackage{geometry}
\usepackage{xcolor}
\usepackage{array}
\usepackage{longtable}
\usepackage{chngcntr}
\counterwithin{figure}{section}
\counterwithin{table}{section}
\usepackage{graphicx}
\usepackage{fancyhdr}
\usepackage{adjustbox}
\usepackage[a4paper, margin=0.8in]{geometry} 
\usepackage{tikz}
% Librerías necesarias
\usetikzlibrary{positioning, shapes, arrows, fit, calc} 

\geometry{margin=2.5cm}

% Definimos el color de los meses y líneas
\definecolor{mescolor}{HTML}{024d50}
\definecolor{linecolor}{HTML}{024d50}
\definecolor{verdeagua}{HTML}{1B9E96}
\definecolor{verdeoscuro}{HTML}{002C2D}
\definecolor{verdemedio}{HTML}{004F4E}

% Cambiar color de secciones
\usepackage{titlesec}
\titleformat{\section}
{\color{mescolor}\normalfont\Large\bfseries}
{}{0pt}{}
\titlespacing*{\section}{0pt}{*2}{*1}

% Línea negra debajo de cada mes
\newcommand{\separador}{\vspace{0.5cm}\noindent\rule{\linewidth}{0.5pt}\vspace{0.5cm}}

% Cambiar color en el índice y tamaño más grande
\usepackage{tocloft}
\renewcommand{\cftsecfont}{\color{mescolor}\bfseries\Large}
\renewcommand{\cftsecpagefont}{\color{mescolor}\bfseries\Large}

% Configuración encabezado y pie de página con líneas de color y largo ajustable
\pagestyle{fancy}
\fancyhf{}
\fancyhead[L]{\textbf{Proyecto BlindAssist}}
\fancyhead[R]{} % Espacio vacío para que no haya logo
\fancyfoot[C]{\thepage}

% Línea de encabezado de color y largo personalizado
\renewcommand{\headrulewidth}{0.4pt}
\renewcommand{\footrulewidth}{0.4pt}

\renewcommand{\headrule}{%
\color{linecolor}\hrule width 1\linewidth height 0.4pt \vskip0pt}
\renewcommand{\footrule}{%
\color{linecolor}\hrule width \linewidth height 0.4pt \vskip0pt}

\begin{document}

\begingroup
\thispagestyle{empty}
\newgeometry{top=0cm,bottom=0cm,left=0cm,right=0cm}

\vspace*{-1.17in}
\noindent\hspace*{-1.02in}
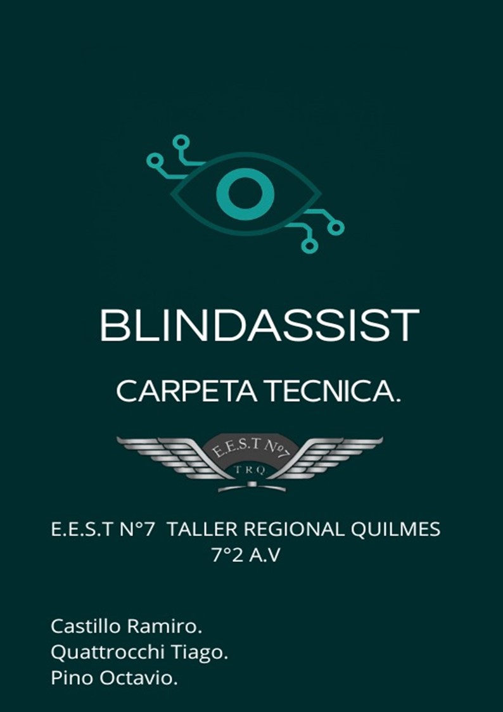
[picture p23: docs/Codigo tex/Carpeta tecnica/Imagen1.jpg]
\noindent
\endgroup
\clearpage

% Índice con numeración desde aquí
\setcounter{page}{1}
\setcounter{tocdepth}{4} % muestra hasta paragraph en el índice
\setcounter{secnumdepth}{4}
\tableofcontents
    \begin{figure}[H]
    \centering % centra la imagen
     % ancho relativo al texto
\end{figure}
\newpage

%--- Introducción ---
\section{Introducción}

\subsection{Integrantes}
\begin{figure}[H]
    \centering
    
\end{figure}
\begin{center}
Castillo Ramiro\\
DNI: 47516171\\
7°2 Aviónica
\end{center}

\begin{figure}[H]
    \centering
    
\end{figure}
\begin{center}

Pino Octavio\\
DNI: 47882634\\
7°2 Aviónica
\end{center}

\begin{figure}[H]
    \centering
    
\end{figure}

\begin{center}
Quattrocchi Tiago\\
DNI: 47510542\\
7°2 Aviónica
\end{center}

\begin{figure}[H]
    \centering
    
    \caption{Grupo BlindAssist}
\end{figure}

\subsection{Docentes a Cargo}
    \begin{center}
        \begin{itemize}
        \item Argüello Gabriel
        \item Bianco Carlos
        \item Carlassara Fabrizio
        \item Medina Sergio
        \item Palmieri Diego
        \end{itemize}
    \end{center}

\subsection{Desarrollo del proyecto}
\subsubsection*{Fecha de Inicio}
14/4/2025
\subsubsection*{Duración del proyecto}
30 Semanas
\subsubsection*{Esfuerzo del proyecto}
Tiempo individual por semana: Máximo de 8 horas de trabajo (240 horas de trabajo en todo el año)

\subsubsection*{Lenguajes utilizados}
\begin{itemize}
\item LaTex
\item CSS
\item HTML
\item Python
\item Javascript
\end{itemize}

\subsubsection*{Programas utilizados}

\begin{itemize}
    \item OverLeaf
    \item Visual Studio Code
    \item Github Desktop
    \item Termius
    \item Proteus 8
    \item AutoCad
    \item UltiMaker
    \item Benewake Software
\end{itemize}

\section{Descripción}

\subsection{Objetivo}
El objetivo de este proyecto es mantener la integridad de las personas ciegas o con algún tipo de discapacidad visual en cualquier tipo de entorno urbano y darles un mayor nivel de conciencia en entornos mas cerrados. Para ello, desarrollamos un dispositivo que mediante reconocimiento por inteligencia artificial y la detección de objetos utilizando tecnología láser para avisar al usuario sobre un obstáculo en frente, por encima de la cadera, la presencia de alguna persona en un espacio cerrado y la cantidad de individuos que se encuentran en el mismo espacio, contando con alertas sonoras y vibratorias que no alteren su percepción y condición actual. Este dispositivo funcionara como una ayuda al bastón que utilizan en su día a día sin modificar su efectividad o tratar de reemplazar su función.

\subsection{Alcance}
\begin{itemize}

\item Cómo objetivo final, querríamos que este este proyecto llegue a ser un prototipo funcional y autónomo, con el menor tamaño posible para la comodidad del usuario. Contar con una IA correctamente entrenada y optimizada en rendimiento, que trabaje en conjunto al área cubierta y sensada por los lasers. Teniendo en cuenta las posibilidades, buscamos que las alertas sensoriales sean claras para el usuario así tiene una experiencia placentera en su día a día.
\end{itemize}

\subsection{Temática}

 \begin{itemize}
 \item Inclusión social: Nuestro proyecto abarca los parámetros presentados en la temática de inclusión social. Esto debido a que el proyecto mismo busca ayudar con el tránsito de las personas con discapacidad tanto en la vía pública cómo lugares cerrados desconocidos. Además, también puede ayudar con su comunicación y vida social, ya que los alerta de las personas que tienen a su alrededor. 
 \end{itemize}
 
\subsection{Problemas a resolver}

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

\subsection{Público beneficiado}
El proyecto está destinado a personas con impedimentos visuales. En el mundo hay 2200 millones de personas con visibilidad reducida, 43,3 millones son no videntes. Esta es la demográfica que será beneficiada directamente por el proyecto, habilitando el tránsito por la vía pública de manera más segura y sin problemas que puedan llegar a afectar su integridad o la rehabilitación a la que están sometidos. Además, al ser un accesorio portable, compacto y difícil de perder u olvidar, no interrumpe en las acciones que pueda realizar el usuario en su vida cotidiana. Este proyecto también beneficiará indirectamente a instituciones privadas como seguros de salud y ART (Aseguradoras de Riesgo del Trabajo), ya que estos pueden ofrecerle como una ayuda al grupo de personas antes descritas. También aplica para la vida cotidiana o la vida pública, ya que se reduce el riesgo de accidentes y la carga que supone a los familiares a la hora de ayudarlo.

\begin{figure}[H]
    \centering
    
    \caption{Tabla de población ciega por continentes.}
\end{figure}

\subsection{Impacto}
 \begin{itemize}
 
\item En un contexto social, este prototipo tiene el potencial de transformar la vida de millones de personas. Como mencionamos anteriormente, más de 40 millones de personas en todo el mundo viven con discapacidad visual. Este impacto no solo afectaría a las personas con esta discapacidad, sino también a sus cuidadores y familiares directos. Es decir, podría beneficiar a una gran cantidad de personas y comunidades. Especialmente en regiones como África, Asia y América del Sur, donde existe un alto número de personas con discapacidad visual, pero donde los recursos y la infraestructura necesarios para facilitar su movilidad y vida cotidiana son limitados.

 \end{itemize}

\subsection{Descripción General}

\begin{itemize}

    \item BlindAssist es un proyecto que busca facilitar el tránsito de los usuarios en la vida cotidiana. A través de un dispositivo colgante que puedan llevar encima o en algún accesorio que mejore su movilidad. Esto lo lograríamos con un conjunto de componentes que trabajan en coordinación. Primero una cámara que detecta elementos específicos, por poner un ejemplo: cestos de basura, señalizaciones, etc. Segundo, unos sensores láser que detectan la proximidad de obstáculos cómo ramas u postes. Cómo tercero, alertas sensoriales a través de audio y vibraciones para alertar al usuario y que este pueda evitar estos inconvenientes.
    
\end{itemize}

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

    \subsection{Diagrama de bloques general}

\begin{figure}
    \centering
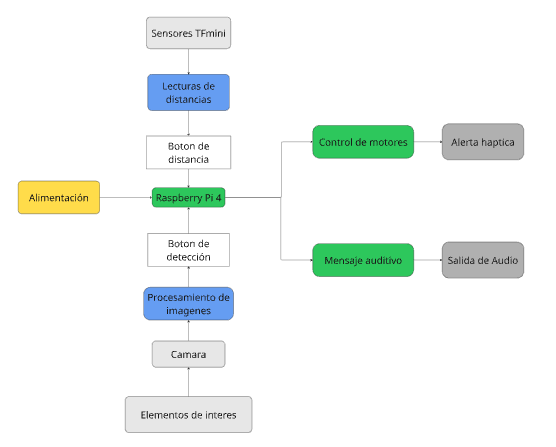
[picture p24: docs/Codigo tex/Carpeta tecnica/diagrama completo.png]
    
    \caption{Diagrama del proyecto BlindAssist}
\end{figure}
    
\end{itemize}

\separador

%--- Hardware ---
\section{Hardware}

\subsection{Raspberry Pi 4}
La Raspberry Pi 4 es una computadora de placa única (SBC) compacta y de bajo consumo que sirve como el "cerebro" de su proyecto. A diferencia de las computadoras de escritorio tradicionales, está diseñada para tareas especializadas y prototipado. Utiliza un procesador Broadcom BCM2711 de cuatro núcleos y una arquitectura ARM, lo que la hace ideal para aplicaciones de robótica y automatización. Su funcionamiento se basa en la ejecución de un sistema operativo, como Raspberry Pi OS, que permite programar y controlar los componentes conectados a sus pines de GPIO (General Purpose Input/Output).
\begin{figure}[H]
\centering

\caption{Modulo Raspberry PI 4}
\end{figure}

\subsubsection{PWM}

El PWM (Pulse Width Modulation) en la Raspberry Pi 4 es una técnica digital para generar señales moduladas en ancho de pulso que permiten controlar la potencia aplicada a dispositivos electrónicos.
En este modelo de placa, el PWM puede implementarse tanto por hardware (pines GPIO dedicados) como por software (emulación mediante librerías como RPi.GPIO o pigpio).

\begin{figure}[H]
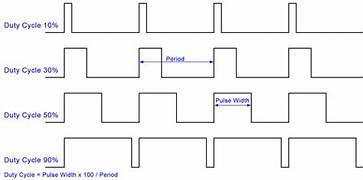
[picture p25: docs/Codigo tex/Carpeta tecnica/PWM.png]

\caption{Duty cicle de PWM}
\end{figure}

\paragraph{Funcionamiento}
El PWM consiste en la generación de una onda cuadrada con dos parámetros principales:

\begin{itemize}
\item Frecuencia (f): cantidad de ciclos por segundo (Hz).

\item Duty cycle (\%): proporción del tiempo en que la señal está en estado alto respecto del periodo total.

La potencia media entregada a la carga es proporcional al duty cycle.
\end{itemize}

Ejemplo:

\begin{itemize}
\item 0\% duty → salida siempre en nivel bajo (0 V).

\item 50\% duty → salida mitad del tiempo en nivel alto.

\item 100\% duty → salida siempre en nivel alto (3,3 V en GPIO).
\end{itemize}

\paragraph{Pines PWM en Raspberry Pi 4}

La Raspberry Pi 4 posee 2 canales PWM de hardware, cada uno con salidas asignables a diferentes GPIO según la configuración.
Algunos pines disponibles:

\begin{itemize}

\item Canal PWM0: GPIO 12 (pin 32), GPIO 18 (pin 12).

\item Canal PWM1: GPIO 13 (pin 33), GPIO 19 (pin 35).

\end{itemize}

\subsubsection{UART}

El UART (Universal Asynchronous Receiver-Transmitter) es un protocolo de comunicación serie asíncrono que transmite y recibe datos bit a bit mediante dos líneas:

\begin{itemize}
    
\item TX (Transmit): envía datos.

\item RX (Receive): recibe datos.

\end{itemize}

\begin{figure} [H]
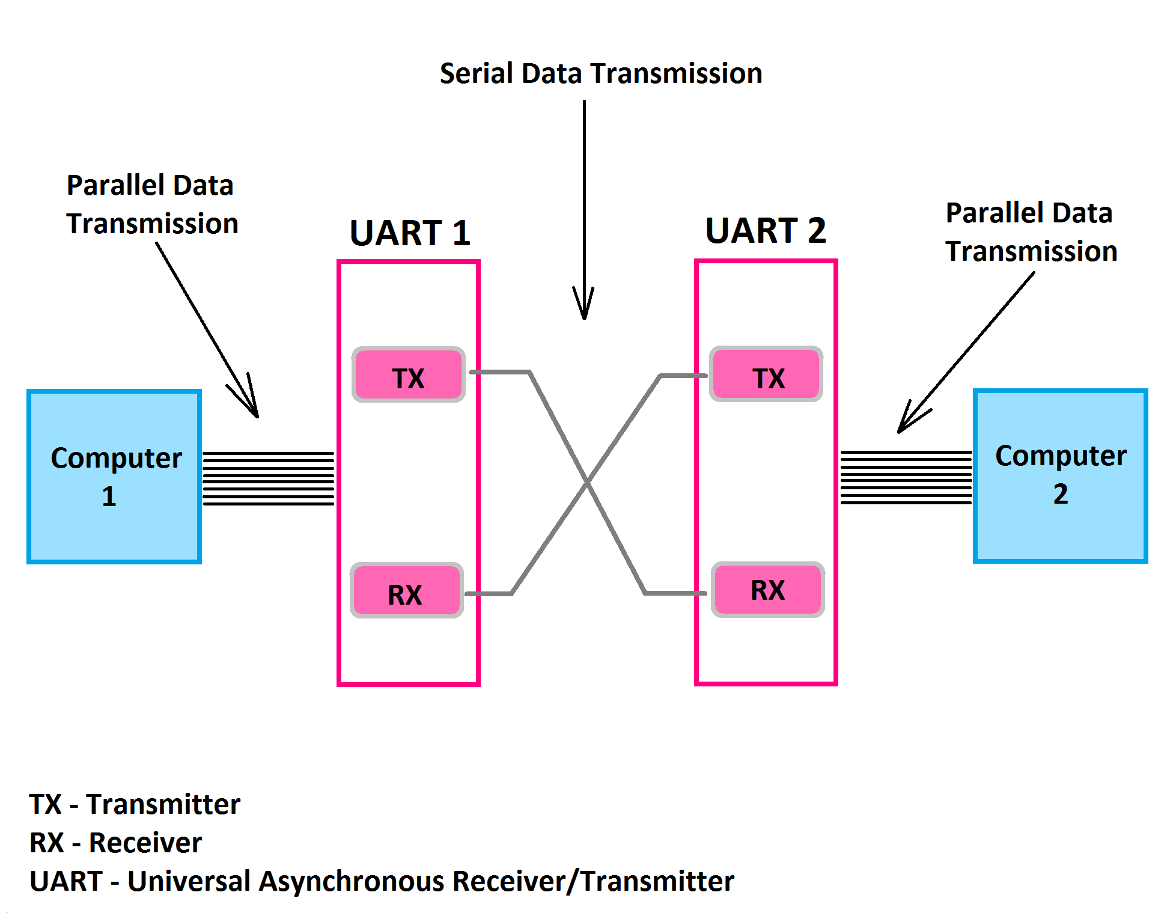
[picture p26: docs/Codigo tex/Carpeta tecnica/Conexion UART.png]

\caption{Conección UART}
\end{figure}

En la Raspberry Pi 4, el UART permite la comunicación directa con módulos, microcontroladores, sensores y periféricos externos, usando niveles lógicos de 3,3 V.

\paragraph{Funcionamiento}

La transmisión UART se basa en una trama de datos que incluye:

\begin{itemize}
\item Bit de inicio (Start bit).

\item Datos (5 a 8 bits).

\item Bit de paridad (opcional).

\item Bit(es) de parada (Stop bit).
\end{itemize}

\begin{figure}[H]
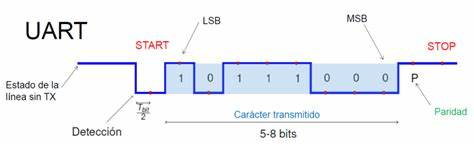
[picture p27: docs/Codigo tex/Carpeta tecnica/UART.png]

\caption{Transmisión de Bits en UART}
\end{figure}

El reloj no se transmite; la sincronización se logra configurando ambas partes con la misma tasa de baudios (baud rate), por ejemplo 9600, 115200 bps.

Es asíncrono, no requiere señal de reloj adicional como en SPI o I²C.

\paragraph{UARTs disponibles en Raspberry Pi 4}

La placa incluye varios controladores UART, aunque no todos están habilitados de forma predeterminada:

\begin{itemize}
\item PL011 (UART principal): más robusto, configurable. Por defecto está mapeado en los pines GPIO14 (TX) y GPIO15 (RX).

\item Mini UART: secundario, con funciones más limitadas.
\end{itemize}

Pines UART por defecto (GPIO – Raspberry Pi 4):

\begin{itemize}
\item GPIO14 (TXD0) → Pin físico 8

\item GPIO15 (RXD0) → Pin físico 10
\end{itemize}

\subsubsection{Esquemático}
\begin{figure}[H]
    \centering

\caption{Esquematico de la Raspberry PI 4}
\end{figure}

\subsubsection{Pinout}
\begin{figure}[H]
    \centering

\caption{Pinout de la Raspberry PI4}
\end{figure}

\subsection{Raspberry PI CAM V1.3}

\begin{figure}[H]
    \centering
    
    \caption{Raspberry PI CAM V1.3}
\end{figure}

La Raspberry Pi Camera Module v1.3 es una cámara oficial diseñada para las placas Raspberry Pi, basada en el sensor OmniVision OV5647 de 5 megapíxeles. Permite capturar imágenes fijas de hasta 2592×1944 píxeles y grabar video en resoluciones de 1080p a 30 fps, 720p a 60 fps y 480p a 90 fps. Se conecta mediante un cable plano CSI (Camera Serial Interface), lo que asegura una transmisión de datos rápida y optimizada.

Este módulo es compacto y ligero, ideal para visión por computadora, robótica, monitoreo y aplicaciones de IoT. Gracias a su integración directa con la Raspberry Pi y la compatibilidad con librerías como Picamera y OpenCV.

\subsubsection{Tablas de parametros}

\begin{table}[H]
\begin{tabular}{|p{4cm}|p{11cm}|}
\hline
\textbf{Parámetro} & \textbf{Descripción} \\ \hline
Tipo de sensor & OmniVision OV5647 Color CMOS QSXGA (5 megapíxeles). \\ \hline
Tamaño del sensor & 3,67 x 2,74 mm. \\ \hline
Contenido de píxeles & 2592 x 1944 píxeles. \\ \hline
Tamaño de píxel & 1,4 x 1,4 µm. \\ \hline
Tamaño de la placa & 25 x 24 mm (sin cable flexible). \\ \hline
\end{tabular}
\caption{Tabla de especificaciones técnicas}
\end{table}

\begin{table}[H]
\begin{tabular}{|p{4cm}|p{11cm}|}
\hline
\textbf{Parámetro} & \textbf{Descripción} \\ \hline
Objetivo & f = 3,6 mm. \\ \hline
Abertura & f/2,9. \\ \hline
Longitud focal & 3,29 mm. \\ \hline
Ángulo de visión & 54° (horizontal) x 41° (vertical). \\ \hline
Campo de visión total & 72,4°. \\ \hline
Campo de visión a 2 m & 2,0 x 1,33 m. \\ \hline
Equivalencia & Lente SLR de 35 mm en formato completo. \\ \hline
Enfoque & Fijo, desde 1 m hasta infinito. \\ \hline
\end{tabular}
\caption{Tabla de parámetros ópticos}
\end{table}

\subsubsection{Rendimiento Fotográfico}
\begin{table}[H]
\begin{tabular}{|p{4cm}|p{11cm}|}
\hline
\textbf{Parámetro} & \textbf{Descripción} \\ \hline
Disparo mínimo & 1/4 s a 5 m. \\ \hline
Resolución de imagen fija & Hasta 2592 x 1944 px (5 MP). \\ \hline
\end{tabular}
\caption{Tabla de rendimiento fotográfico}
\end{table}

\begin{table}[H]
\begin{tabular}{|p{4cm}|p{11cm}|}
\hline
\textbf{Parámetro} & \textbf{Descripción} \\ \hline
Vídeo Full HD & 1080p a 30 fps (códec H.264/AVC). \\ \hline
Vídeo HD & 720p a 60 fps. \\ \hline
Vídeo VGA & Hasta 90 fps. \\ \hline
\end{tabular}
\caption{Tabla de rendimiento de video}
\end{table}

\subsection{TFmini}
El TFmini es un sensor de distancia LiDAR (Light Detection and Ranging). Funciona emitiendo un pulso de láser infrarrojo y midiendo el tiempo que tarda la luz en rebotar en un objeto y regresar al sensor. Esta técnica, conocida como tiempo de vuelo (ToF), le permite calcular la distancia con precisión. Se comunica con la Raspberry Pi a través de interfaces como UART (puerto serie) o I2C, lo que le permite obtener lecturas de distancia de forma rápida y confiable.

\begin{figure}[H]
    \centering
    
    \caption{TFmini S}
\end{figure}

\subsubsection{Descripción General y Principio de Funcionamiento}

El TFmini es un mini módulo LiDAR diseñado para realizar funciones de medición de distancia sin contacto y en tiempo real. Se caracteriza por ofrecer una medición de distancia precisa, estable y de alta velocidad.

El sensor opera bajo el principio de TOF (Time of Flight). El módulo transmite periódicamente una onda de modulación de rayo infrarrojo cercano que se refleja al contactar un objeto. El producto calcula el rango relativo al objeto al medir la diferencia de fase de ida y vuelta (tiempo de vuelo) de la señal.

\begin{figure}[H]
    \centering
    
    \caption{Principio de tiempo de vuelo}
    \label{fig:placeholder}
\end{figure}

\subsubsection{Tablas de parametros}

\begin{table}[H]
\centering
\begin{tabular}{|p{5cm}|p{5cm}|p{5cm}|}
\hline
\textbf{Característica} & \textbf{Parámetro} & \textbf{Notas} \\
\hline
Rango de Operación (Interior) & 0.3 m -- 12 m & Alcance máximo bajo condiciones de interior y pizarra blanca estándar (reflectividad del 90\%). \\
\hline
Precisión de Medición & $\pm 6$ cm (@ 0.3 m - 6 m) / $\pm 1\%$ (@ 6 m - 12 m) &  \\
\hline
Frecuencia (Tasa de Salida) & 100 Hz & Una salida de datos cada 10 ms. \\
\hline
Resolución de Rango & 1 cm &  \\
\hline
Unidad de Distancia por Defecto & cm (centímetros) & Se puede modificar a mm (milímetros) mediante instrucción. \\
\hline
Zona Ciega de Detección & 0 - 30 cm & Los datos en este rango no se consideran fiables. \\
\hline
Ángulo Medio de Recepción ($\beta$) & 1.15° &  \\
\hline
Ángulo Medio de Transmisión & 1.5° &  \\
\hline
\end{tabular}
\caption{Tabla de parámetros y rendimiento}
\end{table}

El rango puede verse afectado por la intensidad de la iluminación ambiental y la reflectividad del objeto. Por ejemplo, en condiciones de deslumbramiento extremo (exterior a mediodía de verano, $\approx 100$ klux) y detección de un objetivo negro (reflectividad del 10\%), el rango efectivo es de 0.3 m a 3 m.

\begin{table}[H]
\centering
\begin{tabular}{|>{\raggedright}p{5cm}|>{\raggedright\arraybackslash}p{5cm}|}
\hline
\textbf{Característica} & \textbf{Parámetro} \\
\hline
Voltaje de Alimentación & 5 V \\
\hline
Corriente Promedio & $\leq 140$ mA \\
\hline
Corriente Pico & 800 mA \\
\hline
Potencia Promedio & $\leq 0.7$ W \\
\hline
Nivel de Comunicación & LVTTL (3.3V) \\
\hline
\end{tabular}
\caption{Tabla de caracteristicas electricas}
\end{table}

El TFmini utiliza el protocolo de comunicación de \textbf{puerto serie (UART)}.

\begin{table}[H]
\centering
\begin{tabular}{|l|c|r}
\hline
\textbf{Protocolo de Comunicación (UART)} & \textbf{Parámetro por Defecto} \\
\hline
Velocidad de Transmisión (Baud rate) & 115200 \\
\hline
Bit de Datos & 8 \\
\hline
Bit de Parada & 1 \\
\hline
Chequeo de Paridad & Ninguno \\
\hline
\end{tabular}
\caption{Tabla de Interfaz y protocolo de comunicación}
\end{table}

\paragraph*{Terminal de Conexión}
Tipo: GH1.25-4P SMT.\\
Pines: GND (Tierra), +5V (Alimentación), RXD (Recepción), TXD (Transmisión).

\paragraph*{Formatos de Salida de Datos}
\begin{itemize}
    \item Formato Estándar (por defecto): Paquete de 9 bytes en formato hexadecimal (HEX). Incluye Distancia (Dist), Intensidad de Señal (Strength), Modo de Distancia (Mode) y Byte de Chequeo (CheckSum).
    \item Formato de Datos Pixhawk: La salida es una cadena de caracteres (string) con la unidad en metros (m). Se utiliza principalmente para la conexión con Pixhawk.
\end{itemize}

\subsubsection{Estructura y Dimensiones}

\begin{itemize}
    \item Carcasa: Fabricada en ABS + PC.
    \item Componentes Externos Clave: Lente de transmisión y Lente de recepción.
    \item Placa de Circuito: La placa de circuito está expuesta en la parte trasera del producto.
    \item Agujero de Montaje: Agujero pasante de 2.35 mm.
    \item Dimensiones : 42 mm (largo) x 15 mm (ancho).
\end{itemize}

\begin{figure}[H]
    \centering
    
    \caption{Proporciones del modulo}
\end{figure}

\subsection{Conversor TTL a USB}

El CP2102 es un controlador de puente USB a UART altamente integrado que permite la conversión directa entre interfaces USB y serie. Este dispositivo es ideal para actualizar sistemas que originalmente utilizaban comunicación RS-232, TTL o RS-485, eliminando la necesidad de puertos seriales tradicionales en PCs modernas.  
Gracias a su tamaño compacto y a la mínima cantidad de componentes externos necesarios, el CP2102 ofrece una solución eficiente, confiable y económica para la comunicación entre ordenadores y dispositivos embebidos.

\begin{figure}[H]
\centering

\caption{Conversor Serie TTL a USB}
\end{figure}

\subsubsection{Funcionamiento}
El CP2102 actúa como un puente entre la interfaz USB 2.0 y los protocolos UART, RS-232 o RS-485 del dispositivo conectado.  
El chip convierte los datos USB en señales serie y viceversa, facilitando la transmisión y recepción asíncrona de datos.  
El módulo no requiere componentes externos USB y es reconocido automáticamente por la mayoría de los sistemas operativos mediante drivers integrados.

\begin{table}[H]
    \centering
\begin{tabular}{|>{\raggedright}p{5cm}|>{\raggedright\arraybackslash}p{8cm}|}
\hline
\textbf{Parámetro} & \textbf{Valor / Descripción} \\
\hline
Chip principal & CP2102 – Puente USB - UART \\
\hline
Interfaz USB & USB 2.0 (Full Speed, 12 Mbps) \\
\hline
Protocolos soportados & TTL, RS-232, RS-485 \\
\hline
Modos de conversión & USB-TTL, USB-RS232, USB-RS485, TTL-RS232, TTL-RS485, RS232-RS485 \\
\hline
Tamaño & 32 mm × 18 mm \\
\hline
Voltajes soportados & 3.3 V / 5 V \\
\hline
Salidas de potencia & 5 V – 500 mA / 3.3 V – 100 mA \\
\hline
Velocidad máxima & Hasta 2 Mbps \\
\hline
Compatibilidad MCU & 8051, STC, AVR, ARM, STM32, DSP, FPGA, MSP430, etc. \\
\hline
Señales adicionales & DTR, RTS (descarga BSL para MSP430) \\
\hline
Protección & Fusible autorrearmable ante sobrecorriente (>500 mA) \\
\hline
\end{tabular}
\caption{Tabla de características técnicas}
\end{table}

\subsubsection{Funciones Destacadas}
\begin{itemize}
    \item Módulo 6 en 1: Conversión bidireccional entre múltiples interfaces serie.
    \item Compatibilidad con 3.3 V y 5 V: Ideal para microcontroladores modernos de bajo voltaje.
    \item Salidas de alimentación integradas: Posibilidad de alimentar el sistema objetivo durante la depuración.
    \item Protección contra sobrecorriente: Fusible de recuperación automática integrado.
    \item Indicadores LED: Visualización del flujo de datos en transmisión y recepción.
    \item Control automático RS-485: No requiere líneas adicionales de control.
    \item Transferencia libre entre protocolos: Conmutación física confiable sin interferencias.
\end{itemize}

\subsection{Fuente Step-down}
Un buck converter (convertidor reductor) es un convertidor DC-DC que reduce una tensión de entrada (Vin) a un valor menor de salida (Vout), manteniendo una alta eficiencia gracias al uso de conmutación en lugar de disipación resistiva.

En este caso, el regulador está basado en el XL4015, un chip controlador step-down con capacidad de hasta 5 A y frecuencia de trabajo en torno a 180 kHz.

\begin{figure}[H]
\centering
 % Imagen de la fuente step-down
\caption{Fuente buck step-down 5V}
\end{figure}

\subsubsection{Funcionamiento}

El XL4015 regula la salida usando PWM de alta frecuencia y los siguientes componentes externos:

\begin{itemize}

\item MOSFET interno (dentro del XL4015): conmuta la corriente desde la entrada hacia la bobina.

\item Inductor (L1): almacena energía en forma de campo magnético y la entrega suavizada a la carga.

\item Diodo Schottky (D1, SS54): permite el flujo de corriente cuando el MOSFET está apagado, garantizando continuidad de corriente.

\item Capacitores (C1, C2, C3, C4, C5): filtran el rizado de entrada y salida.

\item Resistencias R1 y R2 (red de realimentación): forman un divisor que regula la tensión de salida comparándola con la referencia interna del chip.

\item R3 y C6: compensación y estabilidad del lazo de control.

\item Potenciómetro: ajusta la tensión de salida.

\end{itemize}

\subsubsection{Etapas}

\begin{enumerate}
\item Fase de Conducción (MOSFET ON)

El MOSFET interno del XL4015 se enciende. La corriente fluye desde Vin → L1 → C4/C5 → Carga. La bobina almacena energía en su campo magnético, aumentando su corriente.

\item Fase de Retención (MOSFET OFF)

El MOSFET se apaga. La corriente en el inductor no puede caer abruptamente, por lo que el diodo D1 conduce. La energía almacenada en L1 se transfiere hacia la carga y capacitores de salida.

\item Regulación

El divisor resistivo (R1, R2) mide la tensión de salida. Esta señal se compara con una referencia interna (1,25 V típica). El controlador ajusta el duty cycle del PWM del MOSFET interno para mantener la salida estable.
\end{enumerate}

\subsubsection{Parámetros del Esquema}

\begin{figure}

\caption{Esquemático de Fuente buck step-down}
\end{figure}

\begin{itemize}
\item Chip: XL4015 (regulador step-down DC-DC, hasta 5A).

\item Diodo: SS54 (Schottky, rápido y baja caída de tensión).

\item Inductor: 47 µH, soporta varios amperios.

\item Resistencias: R1 (0,05 $\Omega$ detecta corriente, R2 ajusta Vout.

\item Capacitores:

\begin{itemize}

\item Entrada: 220 µF (electrolítico) + 0,1 µF (cerámico) → filtran ruido y picos de corriente.

\item Salida: 220 µF + 0,1 µF → reducen rizado en Vout.

\end{itemize}
\end{itemize}

\subsection{Baterías}
Las baterías Li-Ion cilíndricas tipo 18650 de 3.7 V y 7800 mAh son acumuladores
recargables de alta capacidad, diseñados para aplicaciones que requieren energía confiable,
autonomía prolongada y recarga eficiente. Su formato estandarizado las hace ampliamente
compatibles con dispositivos electrónicos de consumo y proyectos de ingeniería.
Figura 3.14: Baterías de litio

\begin{figure}[H]
    \centering
    
    \caption{Baterías recargables}
    \label{fig:placeholder}
\end{figure}

\subsubsection{Características Técnicas}

\begin{itemize}
\item Química: Ion de Litio (Li-ion).

\item Formato: Cilíndrico 18650 (18 mm diámetro × 65 mm longitud).

\item Voltaje nominal: 3,7 V.

\item Voltaje máximo de carga: 4,2 V.

\item Voltaje de corte (descarga): 2,5–3,0 V.

\item Capacidad nominal: 7800 mAh (7,8 Ah).

\item Energía aproximada: ~28,9 Wh por celda.

\item Conectividad: Terminales planos, aptos para soldadura o porta pilas.
\end{itemize}

\subsection{Motores de vibración}
Los motores de vibración que vamos a utilizar son motores de corriente continua (DC) conocidos como Eccentric Rotating Mass (ERM). Su principio de funcionamiento es muy sencillo pero efectivo: El motor tiene un eje que gira cuando se le aplica energía eléctrica. Lo que crea la vibración es un pequeño peso o masa que está unido al eje, pero no en su centro. Este desplazamiento del centro de masa hace que la rotación sea desequilibrada. A medida que el motor gira a alta velocidad, la masa descentrada genera una fuerza centrífuga que cambia de dirección constantemente. Este movimiento rápido y desequilibrado es lo que produce la vibración que se siente. En muchos dispositivos como es el caso de blindassist que requieren retroalimentación háptica, se usan comúnmente dos motores ERM de diferentes tamaños. Esto permite generar distintos niveles de vibración, desde un temblor fuerte y notorio hasta una vibración suave y sutil, mejorando la experiencia del usuario.

\begin{figure}[H]
    \centering
    
    \caption{Motores de vibración}
\end{figure}

\subsection{Circuito}

\subsubsection{Lista de Componentes}
\begin{longtable}{|>{\raggedright}p{4cm}|c|>{\raggedright\arraybackslash}p{8cm}|}
\hline
\textbf{Componente} & \textbf{Cantidad} & \textbf{Descripción / Función} \\
\hline
Raspberry Pi 4 (J5) & 1 & Microprocesador central, adquisición de datos y control \\
\hline
Sensor TFmini (J1, J2, J3) & 3 & LIDAR para medir distancias \\
\hline
Motores de vibración (J6, J7) & 2 & Generación de señal haptica de alerta \\
\hline
Transistor BC337 (Q1, Q2) & 2 & Etapa de potencia para buzzers \\
\hline
Resistencias 510 $\Omega$ (R1, R2) & 2 & Limitación de corriente en base de transistores \\
\hline
Interruptores (J4, J8) & 2 & Habilitación/deshabilitación manual \\
\hline
Alimentación de baterias (J9, J10) & 2 & Alimentacion de la Raspberry Pi 4 y de los motores de vibración)\\
\hline
\caption{Tabla de la lista de componentes del circuito}
\end{longtable}

%--------------------------
\subsubsection{Descripción del circuito}
\begin{enumerate}
    \item Los sensores TFmini (J1, J2, J3) envían datos de distancia vía UART a la Raspberry Pi 4 (J5).
    \item La Raspberry Pi recibe y procesa la información. Si la distancia medida es menor a un umbral, activa una salida GPIO.
    \item El GPIO activa Q1 o Q2 mediante las resistencias R1 y R2.
    \item Los transistores permiten el paso de corriente hacia los motores (J6, J7), que generan la alerta haptica de vibración.
    \item Los interruptores J4 y J8 permiten habilitar/deshabilitar la deteccion de la IA y seleccionar modos de funcionamiento.
\end{enumerate}

\subsubsection{Esquematico}

\begin{figure}[H]
    \centering

\caption{Esquematico del circuito final}
\end{figure}

\subsubsection{PCB}

\begin{figure}[H]
    \centering

\caption{diseño de impresion del circuito}
\end{figure}

\separador

%--- Firmware ---
\section{Firmware}

\subsection{Detección por IA}
El sistema de visión artificial implementado en este proyecto se basa en el modelo de aprendizaje profundo YOLOv8n.pt para la identificación de objetos en tiempo real, utilizando la cámara de la Raspberry Pi como fuente de datos. La arquitectura del software se estructura en un sistema de Programación Orientada a Objetos (POO). Cada componente lógico (cámara, IA, voz, traductor) está encapsulado en una clase dedicada, lo que facilita el desarrollo, las pruebas y el mantenimiento del sistema de manera modular.

\begin{figure}[H]
\noindent\hspace*{-0.7in}% desplaza hacia la izquierda el origen

\caption{Diagrama de flujo de la deteccion por IA}
\end{figure}

\subsubsection{logica del bucle continuo}
\begin{itemize}
\item Captura frames de video.
\item Analiza cada frame en busca de objetos.
\item Compara las detecciones con las del frame anterior.
\item Emite una alerta de voz solo cuando se detecta un cambio en el entorno (aparición o desaparición de un objeto).
\end{itemize}

\subsubsection{Arquitectura del Código}
El programa se organiza en un conjunto de clases principales:
\begin{itemize}
\item \textbf{Clase Camara:} Gestiona el hardware de la cámara. Utiliza la librería picamera2 para inicializar y capturar un stream de video en vivo. A diferencia de soluciones de un solo fotograma, esta aproximación optimiza el rendimiento y la tasa de fotogramas por segundo (FPS) al mantener el stream de video abierto.
\item \textbf{Clase IA:} Actúa como el motor de inteligencia artificial. Carga el modelo yolov8n.pt y es responsable de analizar los fotogramas capturados. Identifica objetos en una lista predefinida de clases (clases\_permitidas) y filtra las detecciones por un umbral de confianza (CONFIDENCE\_THRESHOLD), asegurando que solo los objetos relevantes y con alta certeza sean considerados.
\item \textbf{Clase Traductor:} Encapsula el diccionario de traducciones. Su única responsabilidad es convertir los nombres de las clases de YOLO (en inglés, como 'person' o 'car') a sus equivalentes en español, permitiendo que el sistema de voz dé las alertas en el idioma del usuario.
\item \textbf{Clase Voz:} Maneja la síntesis de voz. Para garantizar la fiabilidad del audio, utiliza un método robusto basado en la librería subprocess para ejecutar el comando del sistema espeak y vocalizar las alertas. Esta solución es inmune a los problemas de configuración de audio que se presentan a menudo con otras librerías.
\item \textbf{Clase Main:} Es el orquestador principal del sistema. Inicializa todas las demás clases y gestiona el bucle de detección en tiempo real. Su lógica más avanzada reside en el método privado \_\_anunciar\_detecciones, que compara las detecciones actuales con las del último ciclo, emitiendo una alerta de voz únicamente cuando se detecta un cambio. Esto evita la repetición constante de las mismas alertas.
\end{itemize}
El sistema se ejecuta continuamente en un bucle while hasta que el usuario lo interrumpe con Ctrl + C. En ese momento, un bloque finally asegura que el hardware de la cámara se detenga de manera segura para evitar fallos del sistema.

\begin{figure}[H]
\noindent\hspace*{-0.7in}% desplaza hacia la izquierda el origen

\caption{Diagrama de flujo de clases}
\end{figure}

\subsubsection{Componentes de la Implementación}
\paragraph{Librerías}
\begin{itemize}
\item ultralytics: Se utiliza para cargar y ejecutar el modelo de detección de objetos YOLOv8.
\item picamera2: La interfaz oficial para las cámaras de la Raspberry Pi, proporcionando acceso a un flujo de video de alto rendimiento.
\item cv2 (OpenCV): Se usa para el preprocesamiento de los fotogramas, como la conversión de color necesaria antes de pasarlos al modelo de IA.
\item subprocess: La herramienta estándar de Python para ejecutar comandos del sistema, en este caso, el motor de síntesis de voz espeak.
\item os y sys: Permiten la gestión de archivos y el control del sistema, por ejemplo, para verificar la existencia del modelo YOLO antes de su uso.
\end{itemize}

\paragraph{Manejo de Flujo de Datos}
El flujo de información y la lógica de control se manejan principalmente en el método iniciar() de la clase Main:
\begin{itemize}
\item \textbf{Captura:} self.\_\_camara.capturar\_frame() obtiene una imagen del stream de la cámara.
\item \textbf{Análisis:} El frame se pasa a self.\_\_ia.analizar\_imagen(frame), que devuelve un diccionario con los objetos detectados en el fotograma actual.
\item \textbf{Control de Anuncios:} El diccionario se envía al método \_\_anunciar\_detecciones().
\item \textbf{Reproducción de Audio:} Si hay cambios, la clase Voz es invocada a través de self.\_\_voz.hablar(final\_message).
\end{itemize}
La arquitectura del sistema es muy escalable. Al estar modularizado, se podrían añadir fácilmente nuevas clases sin modificar la lógica central del proyecto.

\subsection{Detección por láser}
\subsubsection{Librería TFmini}
Esta sección describe el funcionamiento del código implementado para la lectura simultánea de tres sensores LiDAR TFmini conectados a diferentes puertos UART de una Raspberry Pi 4.

El sistema permite:
\begin{itemize}
\item Recepción continua de datos provenientes de los sensores.
\item Procesamiento y almacenamiento de las distancias medidas.
\item Ejecución paralela mediante hilos (\textit{multithreading}).
\item Acceso centralizado a los valores de distancia para otros módulos del sistema.
\end{itemize}

\textbf{Descripción general del sistema:}
El programa se estructura en cuatro bloques principales:
\begin{itemize}
\item \textbf{Configuración global:} Definición de librerías, estructuras de datos y variables compartidas.
\item \textbf{Módulo de adquisición de datos:} Funciones encargadas de la lectura desde los sensores a través de los puertos UART.
\item \textbf{Gestión de hilos:} Creación de procesos concurrentes para la lectura simultánea de los tres sensores.
\item \textbf{Bucle principal:} Supervisión e impresión periódica de las distancias capturadas.
\end{itemize}
La arquitectura se basa en la comunicación serial estándar (UART) a una velocidad de 115200 baudios, utilizando tramas de 9 bytes emitidas de forma continua por cada módulo TFmini.

\paragraph{Librerías utilizadas:}
\begin{itemize}
\item \textbf{serial (pyserial):} Permite abrir, configurar y manejar los puertos UART para la comunicación con los sensores.
\item \textbf{time:} Proporciona retardos controlados para evitar el uso excesivo de CPU.
\item \textbf{threading:} Facilita la ejecución concurrente de múltiples procesos de lectura.
\end{itemize}

\paragraph{Estructura global de datos:}
\begin{verbatim}
distancias = {
    "uart1": None,
    "uart2": None,
    "uart3": None,
}
\end{verbatim}
El diccionario \texttt{distancias} almacena los últimos valores de distancia válidos recibidos desde cada puerto UART. Inicialmente, los valores son \texttt{None} y se actualizan en tiempo real conforme llegan nuevas mediciones. Este diseño permite el acceso centralizado desde otros módulos del programa.

\paragraph{Función genérica de adquisición de datos:}
\begin{verbatim}
def getTFminiData(port, key_name):
    ser = serial.Serial(port, 115200, timeout=1)
\end{verbatim}

\textbf{Flujo de la función:}
\begin{enumerate}
\item Se abre el puerto serial correspondiente con velocidad de 115200 baudios y un tiempo de espera de 1 segundo.
\item Se ejecuta un bucle infinito que supervisa si existen bytes disponibles en el buffer (\texttt{ser.in\_waiting > 0}).
\item Al detectar datos, se buscan los bytes de cabecera 0x59 0x59, característicos del protocolo TFmini.
\item Si la cabecera es válida, se leen los 7 bytes restantes para completar la trama de 9 bytes.
\item Se extraen los bytes de distancia: el primer byte (\texttt{low}) representa la parte baja y el segundo (\texttt{high}) la parte alta. El cálculo final se realiza mediante:
\[
\text{distance} = \text{low} + (\text{high} \ll 8)
\]
\item Se calcula el \textit{checksum} sumando todos los bytes (excepto el último) junto con la cabecera, y aplicando una máscara de 8 bits:
\[
\text{checksum} = (0x59 + 0x59 + \text{sum(frame[:-1])}) \& 0xFF
\]
\item Si el \textit{checksum} coincide con el último byte de la trama, el valor se considera válido y se almacena en el diccionario global bajo la clave correspondiente.
\item En caso contrario, se descarta la trama y se muestra un mensaje de error.
\item Se incluye un retardo de 5 milisegundos (\texttt{time.sleep(0.005)}) para evitar un consumo excesivo de CPU.
\end{enumerate}

\paragraph{Funciones específicas por puerto UART:}
\begin{verbatim}
def getTFminiData_uart1():
    getTFminiData("/dev/ttyUSB0", "uart1")

def getTFminiData_uart2():
    getTFminiData("/dev/ttyUSB1", "uart2")

def getTFminiData_uart3():
    getTFminiData("/dev/ttyS0", "uart3")
\end{verbatim}
Cada función invoca la función genérica de adquisición con el puerto y la clave correspondientes. Esto permite una escalabilidad sencilla del sistema, facilitando la conexión de nuevos sensores sin alterar la lógica principal.

\paragraph{Gestión de hilos y ejecución principal:}
\begin{verbatim}
if __name__ == '__main__':
    ...
\end{verbatim}
\begin{itemize}
\item Se crean tres hilos (\texttt{Thread}) que ejecutan las funciones \texttt{getTFminiData\_uart1}, \texttt{getTFminiData\_uart2} y \texttt{getTFminiData\_uart3}.
\item Los hilos se definen como \texttt{daemon}, asegurando su finalización automática al detener el programa.
\item Se inician los tres hilos en paralelo mediante \texttt{.start()}, logrando la lectura simultánea de los tres sensores.
\item El bucle principal imprime en consola los valores de distancia almacenados en \texttt{distancias} cada segundo, permitiendo supervisar el correcto funcionamiento de cada módulo.
\item Se gestiona la interrupción manual del usuario (\texttt{KeyboardInterrupt}) para garantizar un cierre seguro del sistema.
\end{itemize}

\begin{figure}[H]
\noindent\hspace*{-0.7in}

\caption{Diagrama de flujo del proceso de lectura de distancias mediante sensores TFmini}
\end{figure}

\subsubsection{Control de Motores}

El código implementa un sistema de control de dos motores mediante modulación por ancho de pulso (PWM) utilizando una Raspberry Pi 4.  
El control se basa en las distancias medidas por tres sensores LiDAR TFmini conectados a los puertos UART de la Raspberry Pi.  
El objetivo del programa es variar la velocidad de los motores en función de la proximidad de obstáculos, generando alertas hapticas (mediante vibraciones) cuando se detectan objetos a menos de 120 cm.

\paragraph{Librerías y Dependencias}

\begin{itemize}
    \item \texttt{time}: Control de tiempos y retardos.
    \item \texttt{threading}: Permite ejecutar lecturas de los tres sensores en paralelo mediante hilos.
    \item \texttt{RPi.GPIO}: Control de los pines GPIO de la Raspberry Pi.
    \item \texttt{TFtest3}: Módulo externo que contiene las funciones de lectura \texttt{getTFminiData\_uart1/2/3} y el diccionario \texttt{distancias}.
\end{itemize}

\paragraph{Configuración del Sistema}

\begin{itemize}
    \item\textbf{Modo GPIO:}

\begin{verbatim}
GPIO.setmode(GPIO.BCM)
\end{verbatim}

\item\textbf{Asignación de Pines PWM:}
\begin{verbatim}
MOTOR_PIN1 = 18
MOTOR_PIN2 = 13
\end{verbatim}

Estos pines son compatibles con PWM por hardware en la Raspberry Pi 4.

\item\textbf{Inicialización de PWM:}
\begin{verbatim}
pwm1 = GPIO.PWM(MOTOR_PIN1, 100)
pwm2 = GPIO.PWM(MOTOR_PIN2, 100)
pwm1.start(0)
pwm2.start(0)
\end{verbatim}

Se inicializan ambas salidas con una frecuencia de \textbf{100 Hz} y un duty cicle del \textbf{0 \%}.
\end{itemize}

\paragraph{Función Auxiliar}
\begin{itemize}
\texttt{calcular\_duty(d):} Esta función traduce la distancia medida (en cm) al porcentaje de ciclo útil del PWM.  
Si el objeto está a menos de \textbf{120 cm}, el duty cycle aumenta proporcionalmente al acercamiento.

\begin{verbatim}
if d < 120:
    return min(100, 120 - d)
\end{verbatim}

Ejemplo de funcionamiento:
\begin{itemize}
    \item Si $d = 100$ cm $\rightarrow$ $duty = 20\%$
    \item Si $d = 50$ cm $\rightarrow$ $duty = 70\%$
\end{itemize}
\end{itemize}

\paragraph{Lógica de Control Principal}
\begin{itemize}

Función central que coordina la lectura de los tres sensores y actualiza los dos motores según las condiciones detectadas.

\textbf{Ciclo de operación:}

\begin{enumerate}
    \item Reinicia el PWM en 0\% al comienzo de cada ciclo.  
    \item Lee las distancias \texttt{d1}(Sensor derecho), \texttt{d2}(Sensor izquierdo), \texttt{d3}(Sensor frontal) desde el diccionario compartido \texttt{distancias}.  
    \item Calcula los valores de duty correspondientes.  
    \item Evalúa las condiciones de proximidad menores a 120 cm.  
\end{enumerate}

\textbf{Casos contemplados:}

\begin{table}[H]
\centering
\begin{tabular}{|c|p{5cm}|p{7cm}|}
\hline
\textbf{Caso} & \textbf{Condición} & \textbf{Acción} \\ \hline
1 & d1 $<$ 120 & Activa PWM0 proporcionalmente. \\ \hline
2 & d2 $<$ 120 & Activa PWM1 proporcionalmente. \\ \hline
3 & d3 $<$ 120 & Ambos motores actúan con el mismo PWM. \\ \hline
4 & d2 y d3 $<$ 120 & Motor 2 titila alternadamente. \\ \hline
5 & d1 y d3 $<$ 120 & Motor 1 titila alternadamente. \\ \hline
6 & d1, d2 y d3 $<$ 120 & Ambos motores al 100\% (alerta crítica). \\ \hline
\end{tabular}
\caption{Casos de control de motores según distancias detectadas.}
\end{table}
\end{itemize}

\paragraph{Ejecución Principal}

\begin{itemize}
El bloque \texttt{if \_\_name\_\_ == "\_\_main\_\_":} inicia la ejecución del programa.

Se crean tres hilos dedicados a la lectura continua de los sensores TFmini:

\begin{verbatim}
t1 = threading.Thread(target=getTFminiData_uart1, daemon=True)
\end{verbatim}

Un cuarto hilo ejecuta la función \texttt{control\_sensores()} para el control de los motores.  
El bucle principal mantiene el programa activo indefinidamente mientras los hilos trabajan en segundo plano.
\end{itemize}

\paragraph{Finalización Segura}
\begin{itemize}
En caso de interrupción manual (Ctrl + C), el programa detiene los PWM y limpia la configuración de los GPIO:

\begin{verbatim}
pwm1.stop()
pwm2.stop()
GPIO.cleanup()
\end{verbatim}

Esto evita errores en ejecuciones posteriores.
\end{itemize}

\begin{figure}[H]
    \centering
    
    \caption{Diagrama de flujo e la logica PWM}
\end{figure}

\subsubsection{Código Final del Sistema Principal ()}

Este script constituye el núcleo operativo del dispositivo, integrando todos los subsistemas de hardware y software: sensores LiDAR TFmini3, cámara, modelo de inteligencia artificial YOLOv8, motores hápticos y síntesis de voz.  
Su propósito es permitir la detección y aviso simultáneo de obstáculos mediante vibración, así como el reconocimiento visual de objetos con retroalimentación auditiva en tiempo real.

\paragraph{Importación de Librerías y Configuración Inicial}
\begin{itemize}
\item \textbf{time, threading:} Controlan los tiempos de ejecución y la ejecución concurrente mediante hilos.
\item \textbf{RPi.GPIO:} Permite la comunicación con los pines GPIO de la Raspberry Pi, tanto para entradas (botones) como salidas (motores).
\item \textbf{subprocess, sys, os:} Facilitan la interacción con el sistema operativo (como ejecutar comandos o validar archivos).
\item \textbf{cv2 y picamera2:} Se utilizan para capturar y procesar imágenes provenientes de la cámara.
\item \textbf{ultralytics.YOLO:} Implementa el modelo de detección de objetos YOLOv8.
\end{itemize}

\begin{verbatim}
import time
import threading
import RPi.GPIO as GPIO
import subprocess
import sys
import os
import cv2
from picamera2 import Picamera2
from ultralytics import YOLO
\end{verbatim}

El programa también importa el módulo externo \texttt{TFmini3}, que gestiona la comunicación serial con los tres sensores LiDAR.  
Si la importación falla (por ejemplo, durante pruebas sin hardware), el sistema genera funciones simuladas con valores fijos, permitiendo verificar la lógica general sin requerir sensores conectados.

\paragraph{Configuración de Hardware y Pines GPIO}
\begin{verbatim}
MOTOR_PIN1 = 12
MOTOR_PIN2 = 13
BUTTON_HAPTIC_PIN = 17
BUTTON_VISUAL_PIN = 27
\end{verbatim}

Los motores de vibración están conectados a pines PWM, mientras que los botones utilizan resistencias \textit{pull-up} internas para evitar lecturas erróneas.  
La configuración general se realiza con:
\begin{verbatim}
GPIO.setmode(GPIO.BCM)
GPIO.setup(..., GPIO.OUT)
GPIO.setup(..., GPIO.IN, pull_up_down=GPIO.PUD_UP)
\end{verbatim}

El PWM de ambos motores se inicializa con una frecuencia de 100 Hz y ciclo de trabajo 0\%, de modo que permanecen inactivos hasta que la lógica háptica los active.

\paragraph{Gestión de Estados Globales y Botones}

Se definen dos variables globales que controlan los modos de funcionamiento:
\begin{itemize}
\item \texttt{estado\_haptico\_activo}: habilita o desactiva el control por vibración.
\item \texttt{estado\_visual\_activo}: habilita o desactiva el módulo de visión e inteligencia artificial.
\end{itemize}

El monitoreo de botones se realiza mediante la función:
\begin{verbatim}
def gestionar_botones():
    ...
\end{verbatim}
La función detecta los cambios de estado de cada botón (por flanco descendente) y alterna el modo correspondiente.  
Esto permite activar o desactivar independientemente las funciones hápticas o visuales mediante una sola pulsación.

\paragraph{Control Háptico mediante Sensores LiDAR}

Esta sección del código traduce las distancias medidas por los tres sensores TFmini3 en señales PWM que controlan la intensidad de los motores.  
El objetivo es proporcionar retroalimentación táctil proporcional a la proximidad de obstáculos.

\begin{verbatim}
def calcular_duty(d):
    if d is None or d >= 120:
        return 0
    return min(100, 120 - d)
\end{verbatim}

Esta función convierte las distancias (en cm) a un ciclo de trabajo PWM de 0 a 100\%, donde objetos más cercanos producen mayor vibración.  
El bucle principal se implementa en \texttt{control\_sensores()}, que ejecuta la lógica condicional de los casos predefinidos:
\begin{itemize}
\item Si los tres sensores detectan un obstáculo a menos de 120 cm, ambos motores vibran al 100\%.
\item Si dos sensores laterales (UART2 y UART3 o UART1 y UART3) detectan obstáculos, el motor correspondiente titila.
\item Si sólo el sensor frontal (UART3) detecta algo, ambos motores vibran de manera uniforme.
\item Si únicamente uno de los sensores laterales detecta proximidad, sólo el motor correspondiente se activa.
\end{itemize}

Esta estructura asegura un lenguaje háptico intuitivo para el usuario, reflejando la ubicación del obstáculo con patrones de vibración diferenciados.

\paragraph{Módulos de Detección Visual e Inteligencia Artificial}

El sistema visual se implementa mediante un conjunto de clases modulares:

\begin{itemize}
\item \textbf{Camara:} Gestiona la inicialización, captura y cierre del flujo de video mediante \texttt{Picamera2}. Convierte los fotogramas a formato BGR compatible con OpenCV.
\item \textbf{Voz:} Usa el motor \texttt{espeak} para generar avisos por voz sin bloquear la ejecución principal. Se ejecuta en hilos secundarios para mantener la fluidez del sistema.
\item \textbf{Traductor:} Contiene un diccionario que traduce las etiquetas de detección de YOLO (en inglés) al español, mejorando la comprensión de los avisos.
\item \textbf{IA:} Carga el modelo YOLOv8 preentrenado y filtra las detecciones según su nivel de confianza y tipo de objeto permitido.
\end{itemize}

La clase principal \textbf{AsistentePrincipal} organiza todos los módulos visuales.  
Durante la ejecución, captura continuamente imágenes, las analiza con el modelo YOLO y anuncia los cambios detectados (aparición o desaparición de objetos) mediante voz.  
El método interno \texttt{\_\_anunciar\_detecciones()} compara los objetos actuales con los detectados previamente y genera mensajes cortos como:
\textit{“Una persona.”, “Dos Personas.” o “Persona fuera.”}

\paragraph{Lógica Multihilo y Ejecución Simultánea}

Gracias a la librería \texttt{threading}, el sistema puede ejecutar múltiples procesos al mismo tiempo:
\begin{itemize}
\item Un hilo para cada sensor LiDAR.
\item Un hilo para la gestión de botones físicos.
\item Un hilo para el control háptico (PWM).
\item Un hilo para la detección visual (cámara e IA).
\end{itemize}

Esto permite que el usuario reciba alertas táctiles y auditivas sin interrupciones, incluso mientras la cámara analiza el entorno.

\paragraph{Función Principal (\texttt{main})}

\begin{verbatim}
def main():
    asistente = AsistentePrincipal()
    ...
\end{verbatim}

La función principal inicializa todos los hilos mencionados y mantiene el programa en ejecución indefinidamente.  
En caso de interrupción manual (\texttt{Ctrl + C}), el sistema detiene el PWM, limpia los pines GPIO y libera los recursos del hardware, garantizando un apagado seguro.

\begin{figure}[h!]
    \centering
    \small % Usamos fuente pequeña para aprovechar el espacio
    
    % Definición de estilos de nodos usando \tikzset
    \tikzset{
        startend/.style={ellipse, draw, fill=green!30, text width=6em, text centered, minimum height=1em},
        thread/.style={rectangle, draw, fill=orange!30, text width=8em, text centered, rounded corners, minimum height=2em, align=center},
        module/.style={rectangle, draw, fill=blue!20, text width=9em, text centered, rounded corners, minimum height=2em, align=center},
        data/.style={trapezium, draw, fill=yellow!20, text width=6em, text centered, minimum height=1em, align=center, inner xsep=5pt},
        decision/.style={diamond, draw, fill=red!20, text width=5em, text badly centered, inner sep=0pt, aspect=1.5, align=center},
        hardware/.style={rectangle, draw, fill=gray!40, text width=6em, text centered, minimum height=1em, align=center},
        line/.style={draw, -latex'},
        fitbox/.style={rectangle, draw, dashed, thick, inner sep=10pt, text width=12em, align=left} 
    }

    \begin{tikzpicture}[node distance = 0.8cm, auto, scale=0.9, transform shape]\label{blindassist_vertical_flow_perfect}
    
        % --- SECCIÓN 1: INICIO y HILOS PRINCIPALES ---
        \node [startend] (main_start) {MAIN START};
        \node [module, below=of main_start, node distance=1.2cm] (init) {Inicialización General (GPIO, PWM, Clases)};
        
        % Hilos de Lectura LiDAR
        \node [thread, below=of init] (thread_l_grp) {Hilos 1, 2, 3: Lectura Asíncrona de LiDARs};
        
        % Thread Háptico
        \node [thread, below=of thread_l_grp] (ctrl_thread) {Hilo 4: control\_sensores (Lazo Háptico)};
        
        % Thread Visual/IA
        \node [thread, below=of ctrl_thread, yshift=-0.5cm] (assist_thread) {Hilo 5: Asistente Principal (Lazo Visual/IA)};
        
        % --- SECCIÓN 2: LÓGICA HÁPTICA ---
        
        \node [module, below left=1.0cm and 0.5cm of ctrl_thread] (calc_duty) {Calcular Duty Cycle (Distancia a PWM)};
        \node [decision, below=of calc_duty] (case_logic) {Evaluar Casos de Proximidad (Prioridad Lógica)};
        \node [hardware, below=of case_logic] (motores) {Activar/Modular Motores (PWM)};
        
        % Dibuja la caja de LÓGICA HÁPTICA
        \node [fitbox, fit=(calc_duty) (motores) (ctrl_thread)] (fit_haptic) {};
        \node at (fit_haptic.north west) [anchor=north west, xshift=5pt, yshift=-5pt, font=\bfseries] {LÓGICA HÁPTICA};

        % Conexiones Hápticas
        \path [line] (ctrl_thread) -- (calc_duty);
        \path [line] (calc_duty) -- (case_logic);
        \path [line] (case_logic) -- (motores);
        
        % Bucle Háptico (Desvío completo a la izquierda)
        \coordinate (loop_haptic_corner) at ($(motores.west) + (-1.5cm, 0)$);
        \path [line] (motores.west) -| (loop_haptic_corner) |- (ctrl_thread.west);

        % --- SECCIÓN 3: LÓGICA VISUAL / IA ---
        
        % AJUSTE: Aumentar text width para que el texto Camara.capturar_frame() quepa bien
        \node [module, below right=1.0cm and 0.5cm of ctrl_thread, text width=10.5em] (cam_capt) {Camara.capturar\_frame()};
        \node [module, below=of cam_capt] (ia_analize) {IA.analizar\_imagen() (YOLOv8)};
        \node [module, below=of ia_analize] (announce_check) {Comparar y Generar Anuncio};
        
        \node [decision, below=of announce_check] (changes) {Anuncio Necesario?};
        
        \node [module, right=of changes, node distance=2.5cm, yshift=-0.5cm] (voice_speak) {Voz.hablar(Mensaje) (Hilo asíncrono)};
        
        \node [module, below=of changes] (update_state) {Actualizar Estado y Esperar (time.sleep)};
        
        % Dibuja la caja de LÓGICA VISUAL
        \node [fitbox, fit=(cam_capt) (update_state) (voice_speak) (assist_thread)] (fit_visual) {};
        \node at (fit_visual.north west) [anchor=north west, xshift=5pt, yshift=-5pt, font=\bfseries] {LAZO VISUAL / IA};

        % Conexiones Visuales
        \path [line] (assist_thread) -- (cam_capt);
        \path [line] (cam_capt) -- (ia_analize);
        \path [line] (ia_analize) -- (announce_check);
        \path [line] (announce_check) -- (changes);
        
        % Lógica de Anuncio de Voz
        \path [line] (changes) -- node[above] {Sí} (voice_speak);
        \path [line] (changes) -- node[left] {No} (update_state);
        \path [line] (voice_speak) |- (update_state); 

        % Bucle Visual (AJUSTE: Redirigido para no cruzar voice_speak)
        \coordinate (loop_visual_bend) at ($(voice_speak.south) + (1.5cm, -0.5cm)$); % Punto de giro debajo de voice_speak
        \path [line] (update_state.east) -- ++(1.5cm, 0) |- (loop_visual_bend) |- (cam_capt.east);
        
        % --- SECCIÓN 4: CONEXIONES EXTERNAS Y CIERRE ---
        
        \node [startend, below=of update_state, node distance=2.5cm] (main_end) {MAIN END (Cleanup)};

        % Conexiones de Hardware (Evitan cruces)
        \node [hardware, above left=1.2cm and 2.5cm of init] (lidar_h) {Sensores LiDAR (Entrada)};
        \node [hardware, above right=1.2cm and 2.5cm of init] (camera_h) {Cámara (Entrada)};
        
        \path [line, draw=gray] (lidar_h) -- (thread_l_grp);
        \path [line, draw=gray] (camera_h) -- (assist_thread);

        % Conexión del flujo principal al final
        \path [line] (update_state) -- (main_end); 

    \end{tikzpicture}
    \caption{Diagrama de Bloques de BlindAssist (Optimizado para A4 Vertical y sin Cruces)}
\end{figure}

\paragraph{Procedimiento de Despliegue y Arranque Automático}

\begin{itemize}
Un aspecto fundamental del proyecto fue garantizar que el sistema se ejecute de forma automática al encender la Raspberry Pi. Para ello, se descartó el uso de \texttt{crontab}, que presentaba fallos al iniciar el entorno virtual de Python, y se optó por \texttt{systemd}, la herramienta moderna de Linux para gestionar servicios.
\end{itemize}

\paragraph{Archivo de Servicio: blindassist.service}

\begin{itemize}
El archivo \texttt{blindassist.service}, ubicado en \texttt{/etc/systemd/system/}, define cómo y cuándo debe ejecutarse el programa principal. Su contenido clave es:
\end{itemize}

\begin{verbatim}
[Unit]
Description=Servicio de Asistencia Visual - Arranque Automatico
After=network.target multi-user.target

[Service]
Type=idle
User=blindassist
ExecStart=/bin/bash -c "sleep 10 && 
/home/blindassist/repo/firmware/.venv/bin/python 
/home/blindassist/repo/firmware/control_principal.py"
Restart=always
RestartSec=5

[Install]
WantedBy=multi-user.target
\end{verbatim}

Este archivo cumple con tres funciones principales:
\begin{itemize}
    \item \textbf{Arranque Diferido:} El comando \texttt{sleep 10} garantiza que el sistema operativo haya terminado de cargar antes de iniciar el script.
    \item \textbf{Ejecución en Segundo Plano:} El programa se ejecuta como un servicio del sistema, independiente de sesiones de usuario.
    \item \textbf{Robustez:} En caso de fallo, el servicio se reinicia automáticamente gracias a las directivas \texttt{Restart=always} y \texttt{RestartSec=5}.
\end{itemize}

\separador

%--- Diseño ---
\section{Diseño}

\subsection*{ Prototipo 3D}

\subsection*{ Materiales Utilizados / Programas}
\begin{itemize}
\item Filamento de impresión 3D PLA.
\item Tornillos 1/8
\item AutoCAD
\end{itemize}

\subsection{Diseño General}
El diseño corresponde a un prototipo de carcasa destinado a integrar de forma eficiente los sensores y componentes del proyecto. Su geometría incluye un frente inclinado en forma triangular, que permite optimizar los ángulos de medición de los LIDAR y ampliar su campo de detección en entornos urbanos. También incorpora un orificio frontal para la cámara y tres ranuras específicas para los LIDAR, lo que asegura una orientación precisa y funcional. El sistema de cierre se resuelve mediante anclajes en el borde del cuerpo y orejas externas para tornillos, lo que garantiza un ajuste firme y facilita el mantenimiento. A nivel general, el prototipo busca maximizar el aprovechamiento del espacio interno, mejorar la disposición de los sensores y proteger los componentes electrónicos. Es importante remarcar que se trata de un prototipo en evolución, sujeto a mejoras tanto en la disposición interna como en la ergonomía y robustez del ensamble.

\subsection{Comparaciones entre Versiones}
\begin{itemize}
\item \textbf{Espacio interno:} El primer prototipo no contaba con el espacio suficiente para albergar todos los componentes electrónicos. En el segundo, se corrigieron dimensiones y proporciones, logrando una organización más adecuada del volumen interno.
\item \textbf{Ranuras para sensores LIDAR:} En el primer modelo, las ranuras eran más genéricas y no contemplaban bien la orientación de los sensores. El segundo prototipo introdujo tres ranuras específicas para los LIDAR, con un frente inclinado que mejora el ángulo de detección.
\item \textbf{Relieves y fijaciones internas:} El primer y segundo prototipo carecían de soporte interno para los componentes. En el tercer prototipo, que exteriormente mantiene la misma geometría, se añadieron relieves interiores para que los LIDAR queden bien posicionados y se incorporaron finalmente los anclajes para fijar las plaquetas electrónicas, permitiendo un montaje más firme y seguro.
\item \textbf{Sistema de cierre}: Desde el segundo prototipo ya se contemplaban orejas externas para tornillería, pero en el prototipos siguiente se mejoró la definición de los encastres en el borde del cuerpo, logrando un cierre más sólido.
\item La serie de prototipos muestra una mejora constante en la funcionalidad y organización interna de la carcasa. El primer prototipo permitió validar dimensiones generales. El segundo resolvió la correcta orientación de los LIDAR con el frente inclinado y el aumento de espacio. El tercero introdujo finalmente los relieves interiores y fijaciones internas, mejorando la integración de los componentes. Este proceso iterativo confirma que el diseño está en el camino correcto, pero aún con margen para seguir perfeccionando aspectos de robustez estructural, ensamblaje y usabilidad.
\end{itemize}

\subsection{Imágenes}
\subsubsection{Primer Prototipo}
\begin{figure}[H]
    \centering
    
\end{figure}
\begin{figure}[H]
    \centering
    
    \caption{Primera tapa}
\end{figure}

\subsubsection{Segundo Prototipo}

\begin{figure}[H]
    \centering
    
    \caption{Tapa y base}
\end{figure}
\separador

%--- Redes sociales ---
\section{Redes sociales}

\subsection{Página web}
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

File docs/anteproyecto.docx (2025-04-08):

BLINDASSIST

Presentación de anteproyecto

Título del proyecto:

Elegimos el nombre BlindAssist porque encapsula la esencia y el propósito fundamental de nuestro proyecto. 'Blind' (ciego en inglés) representa claramente a la población objetivo a la que nos dirigimos: personas con discapacidad visual. 'Assist' (asistir) refleja la función principal de nuestra solución: proporcionar ayuda y mantener la integridad del usuario al transitar la vía pública.

Integrantes:

Integrantes:

- Castillo Ramiro
- Pino Octavio Lautaro
- Quattrocchi Tiago Luca

Objetivo del proyecto:

El objetivo de este proyecto es mantener la integridad de las personas ciegas o con discapacidad visual en entornos urbanos. Para ello, se desarrollará una riñonera, equipada con una cámara, un sistema de inteligencia artificial y láseres LIDAR que avisan al usuario sobre un obstáculo en frente, contando con alertas sonoras y vibratorias para cumplir este propósito. Con este proyecto, se busca facilitar el desplazamiento de personas con discapacidad visual, brindándoles seguridad en la vía pública.

Utilidades del proyecto:

El proyecto está destinado a personas con impedimentos visuales. En el mundo hay 2200 millones de personas con visibilidad reducida, 43,3 millones son no videntes. Esta es la demográfica que será beneficiada directamente por el proyecto, habilitando el tránsito por la vía pública de manera más segura y sin problemas que puedan llegar a afectar su integridad o la rehabilitación a la que están sometidos. Además, al ser un accesorio portable, compacto, difícil de perder u olvidar y puede servir para guardar bienes no interrumpe en las acciones que pueda realizar el usuario en su vida cotidiana.

Este proyecto también beneficiará indirectamente a instituciones privadas como seguros de salud y ART (Aseguradoras de Riesgo del Trabajo), ya que estos pueden ofrecerlo como una ayuda al grupo de personas antes descritas. También aplica para la vida cotidiana o la vida pública, ya que se reduce el riesgo de accidentes y la carga que supone a los familiares a la hora de ayudarlo.

Descripción del funcionamiento:

BlindAssist integra una Pi Camera que captura imágenes en tiempo real del entorno del usuario. Estas imágenes son procesadas por una Raspberry Pi 4, que emplea un modelo de Machine Learning entrenado para reconocer distintos elementos del entorno, como postes, señales, árboles, vehículos mal estacionados y cestos de basura. Una vez identificados, el sistema reproduce audios descriptivos en los auriculares conectados al dispositivo.
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

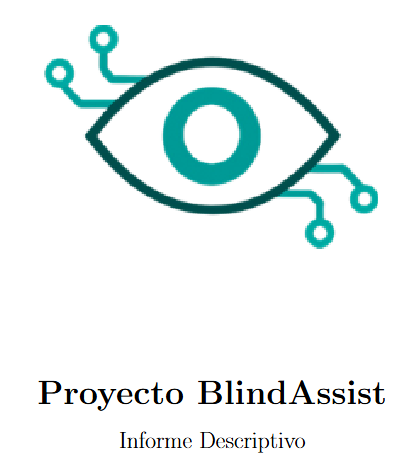
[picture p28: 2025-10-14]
docs/Codigo tex/Carpeta de campo/informe.png

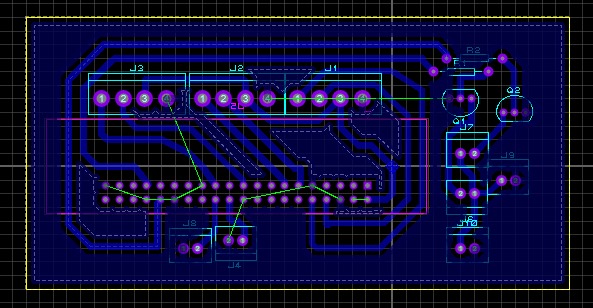
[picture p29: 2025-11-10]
Hardware/PLACAS PCB/PLACA1.jpg

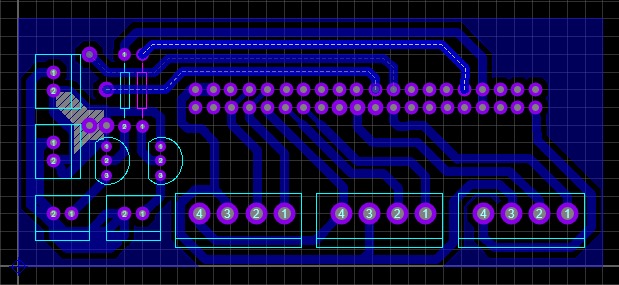
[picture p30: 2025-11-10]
Hardware/PLACAS PCB/PLACA2.JPG

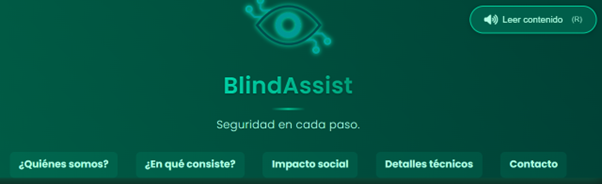
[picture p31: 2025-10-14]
docs/Codigo tex/Carpeta de campo/Imagen10.png

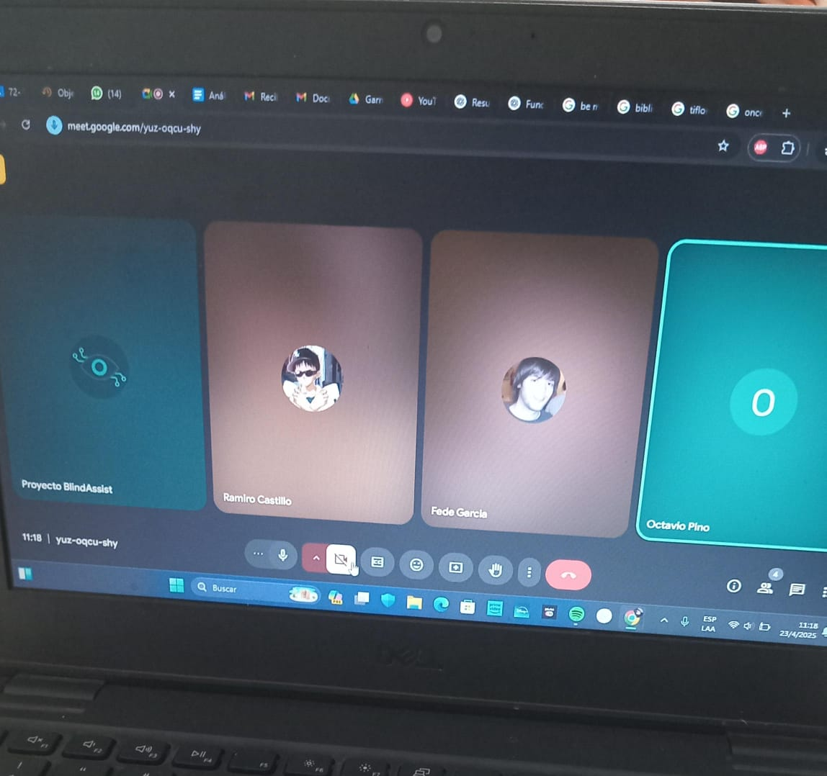
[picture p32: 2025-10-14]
docs/Codigo tex/Carpeta de campo/Reunion.png

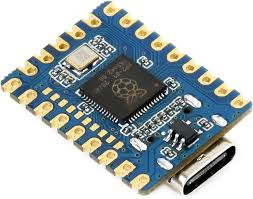
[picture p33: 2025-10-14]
docs/Codigo tex/Carpeta de campo/RP2040.png

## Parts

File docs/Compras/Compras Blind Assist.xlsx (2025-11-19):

Planilla de compras Proyectos de 7mo Aviónica
Nombre del Proyecto |  | Blind Assist |  | Alumnos Responsables: |  |  | AVIÓNICA
 |  |  |  | Ramiro Castillo | castilloramiro06@gmail.com
 |  |  |  | Tiago Quatrocchi | tiago4cchi@gmail.com
Item | Cant. | Nombre del producto | Detalle del pedido | Link: | Precio por unidad | Sub Total | Fecha de solicitud | Tutores |  | Jefe de Área |  | Cooperadora
 |  |  |  |  |  |  |  | Aprobado | Fecha de aprobación | Aprobado | Fecha de aprobación | Estado | Fecha de entrega
1 | 1 | Fuente Switching Buck Step Down Dc Dc 5a | Fuente switching buck step-down DC-DC 5A, convierte voltajes altos en 5 V eficientes para alimentar dispositivos de alto consumo. | https://www.mercadolibre.com.ar/fuente-switching-buck-step-down-dc-dc-5a-arduino/p/MLA46825419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 | $7983.00 | $7983.00 | 2025-05-08 14:38 | VERDADERO | 2025-05-08 14:50 | VERDADERO | 2025-05-08 14:50 | Comprado
2 | 1 | Raspberry Pi 4 | Minicomputadora de alto rendimiento usada para desarrollo y control de sistemas embebidos. | https://tienda.starware.com.ar/producto/placa-sbc-raspberry-pi-4-model-b-8gb-ram/ |  | $0.00 | 2025-05-07 20:13 |  |  |  |  | Presupuestando
3 | 2 | TF mini S LIDAR | sensor de distancia basado en tecnología láser, útil para medición precisa y detección de objetos. | https://tienda.starware.com.ar/producto/modulo-sensor-rango-lidar-tfmini-s-laser/ | $114079.00 | $228158.00 | 2025-05-07 20:13 | VERDADERO | 2025-08-05 09:19 | VERDADERO | 2025-08-05 09:19 | Presupuestando
4 | 2 | Rspberry PI Cam V2 | Cámara oficial para Raspberry Pi, utilizada para captura de imágenes y video | https://tienda.starware.com.ar/producto/camara-modulo-raspberry-pi-cam-v13-5mp-pi-a2345zero/ | $11389.00 | $22778.00 | 2025-05-07 20:13 | VERDADERO | 2025-09-23 12:32 | VERDADERO | 2025-09-23 12:32 | Presupuestando
5 | 2 | Caja X 2u. Pilas 3.7v 7800 Mah | Las baterías Li-ion son recargables, de alta densidad energética y comúnmente usadas en dispositivos electrónicos por su eficiencia y larga vida útil. | https://articulo.mercadolibre.com.ar/MLA-1413009421-caja-x-2u-pilas-37v-7800-mah-_JM | $6000.00 | $12000.00 | 2025-05-08 10:34 | VERDADERO | 2025-05-08 14:50 | VERDADERO | 2025-05-08 14:50 | Comprado
6 | 2 | Portapilas Porta Pilas Doble 2 Pilas Bateria 18650 Esquelet | Un portador de pilas doble es un soporte diseñado para alojar y conectar dos pilas, facilitando su uso en circuitos eléctricos. | https://articulo.mercadolibre.com.ar/MLA-1292492331-portapilas-porta-pilas-doble-2-pilas-bateria-18650-esquelet-_JM | $3800.00 | $7600.00 | 2025-05-08 10:52 | VERDADERO | 2025-05-08 14:50 | VERDADERO | 2025-05-08 14:50 | Comprado
7 | 2 | Adaptador seriettl a uart | El CP2102 es un controlador de puente USB a UART, que proporciona una solución sencilla para actualizar diseños RS-232 a USB utilizando un mínimo de componentes y espacio PCB. Viene con un controlador de función de velocidad completa USB 2.0. No se necesitan componentes USB externos. | https://tienda.starware.com.ar/producto/modulo-conversor-usb-a-serie-diy-cp2102-ttl-485-33v-5v/ | $5729.00 | $11458.00 | 2025-09-23 10:07 | VERDADERO | 2025-09-23 11:25 | VERDADERO | 2025-09-23 11:25 | Presupuestando
8 |  |  |  |  |  | $0.00 |  |  |  |  |  | Presupuestando
9 |  |  |  |  |  | $0.00 |  |  |  |  |  | Presupuestando
10 |  |  |  |  |  | $0.00 |  |  |  |  |  | Presupuestando
11 |  |  |  |  |  | $0.00 |  |  |  |  |  | Presupuestando
12 |  |  |  |  |  | $0.00 |  |  |  |  |  | Presupuestando
13 |  |  |  |  |  | $0.00 |  |  |  |  |  | Presupuestando
14 |  |  |  |  |  | $0.00 |  |  |  |  |  | Presupuestando
15 |  |  |  |  |  | $0.00 |  |  |  |  |  | Presupuestando
16 |  |  |  |  |  | $0.00 |  |  |  |  |  | Presupuestando
17 |  |  |  |  |  | $0.00 |  |  |  |  |  | Presupuestando
18 |  |  |  |  |  | $0.00 |  |  |  |  |  | Presupuestando
19 |  |  |  |  |  | $0.00 |  |  |  |  |  | Presupuestando
20 |  |  |  |  |  | $0.00 |  |  |  |  |  | Presupuestando
21 |  |  |  |  |  | $0.00 |  |  |  |  |  | Presupuestando
22 |  |  |  |  |  | $0.00 |  |  |  |  |  | Presupuestando
23 |  |  |  |  |  | $0.00 |  |  |  |  |  | Presupuestando
24 |  |  |  |  |  | $0.00 |  |  |  |  |  | Presupuestando
25 |  |  |  |  |  | $0.00 |  |  |  |  |  | Presupuestando
26 |  |  |  |  |  | $0.00 |  |  |  |  |  | Presupuestando
27 |  |  |  |  |  | $0.00 |  |  |  |  |  | Presupuestando
28 |  |  |  |  |  | $0.00 |  |  |  |  |  | Presupuestando
29 |  |  |  |  |  | $0.00 |  |  |  |  |  | Presupuestando
30 |  |  |  |  |  | $0.00 |  |  |  |  |  | Presupuestando
 |  |  |  |  | Total: | $289977.00 |  | Gastado: | $27583.00

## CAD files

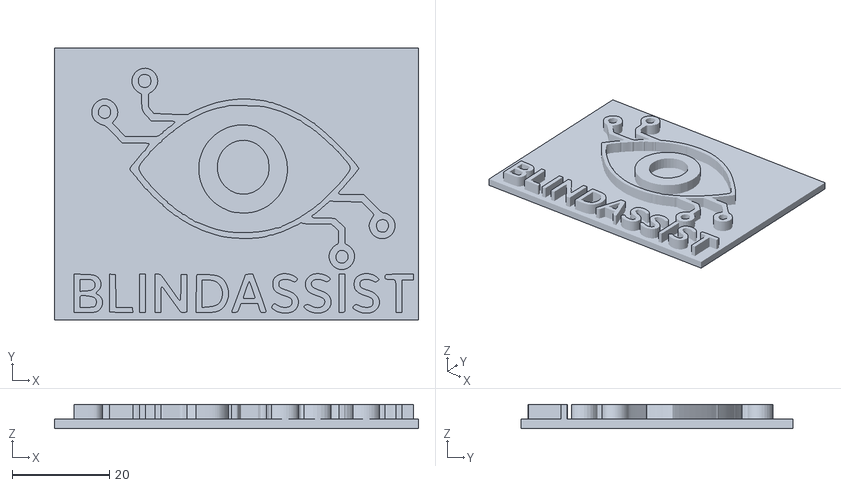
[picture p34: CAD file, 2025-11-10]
Hardware/Diseño3d/BlindAssistLogo.stl
75.0 x 56.0 x 5.00

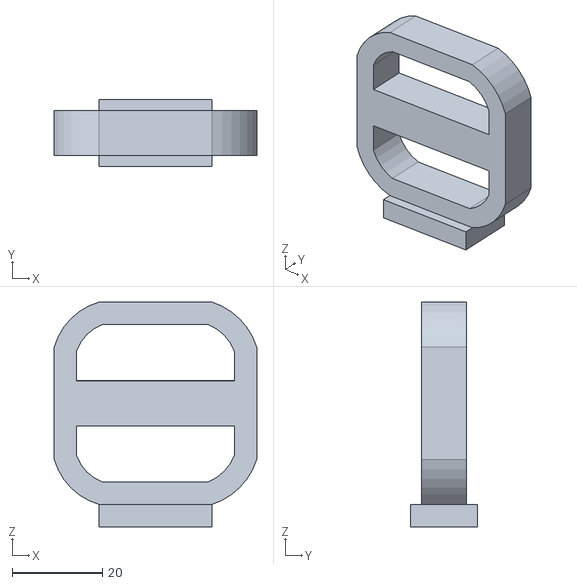
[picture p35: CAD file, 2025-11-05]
Hardware/Diseño3d/agarres.stl
45.0 x 15.0 x 50.0

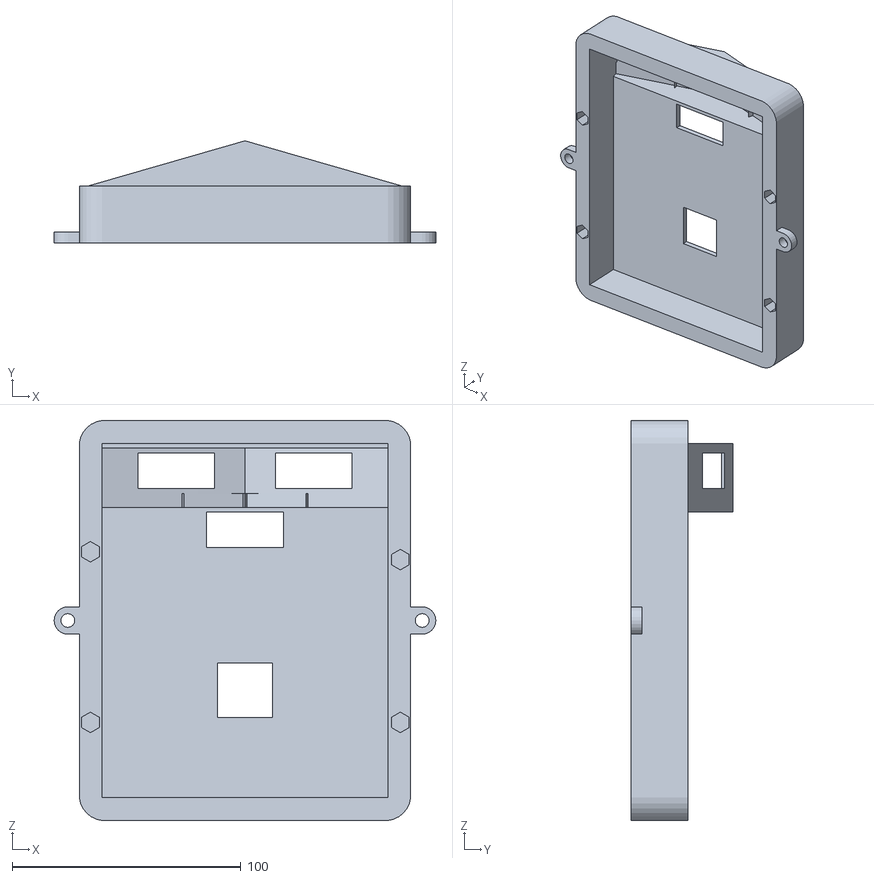
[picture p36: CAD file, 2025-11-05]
Hardware/Diseño3d/tapafinal.stl
167.0 x 44.8 x 175.0

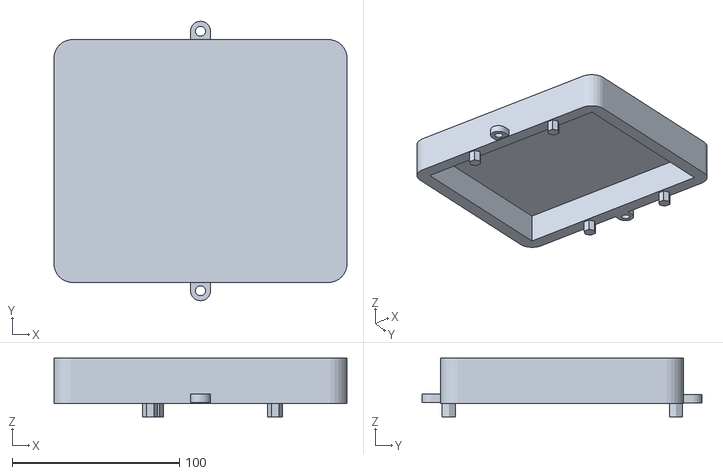
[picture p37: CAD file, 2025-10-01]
Hardware/Diseño3d/segundo modelo.stl
175.0 x 167.0 x 35.1

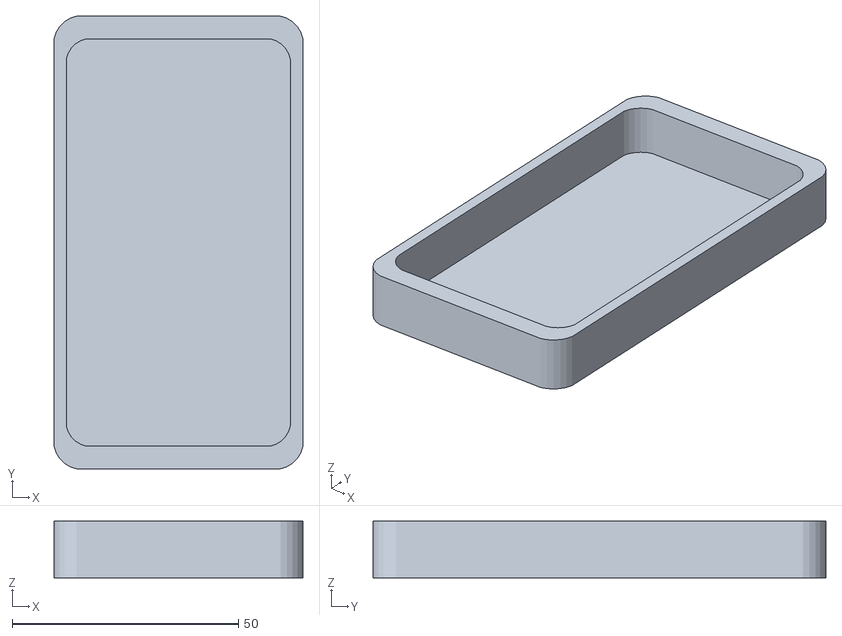
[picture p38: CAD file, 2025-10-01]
Hardware/Diseño3d/primer modelo1.stl
55.0 x 100.0 x 12.5

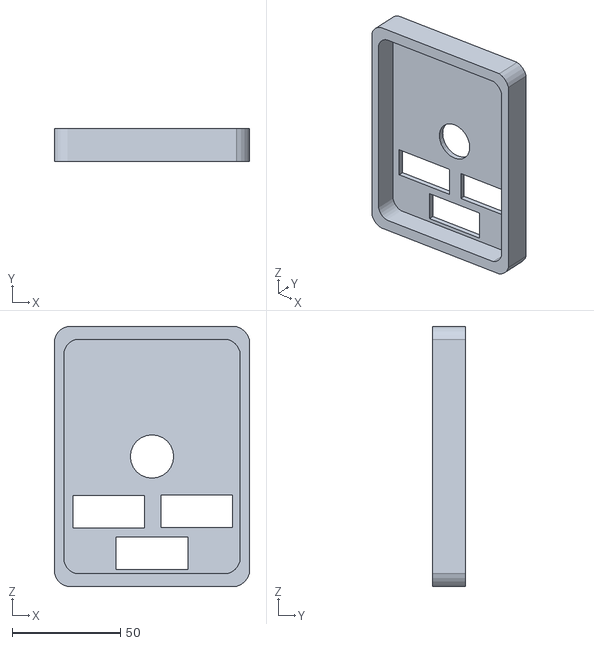
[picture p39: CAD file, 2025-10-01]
Hardware/Diseño3d/primermodelo2.stl
90.0 x 15.0 x 120.0

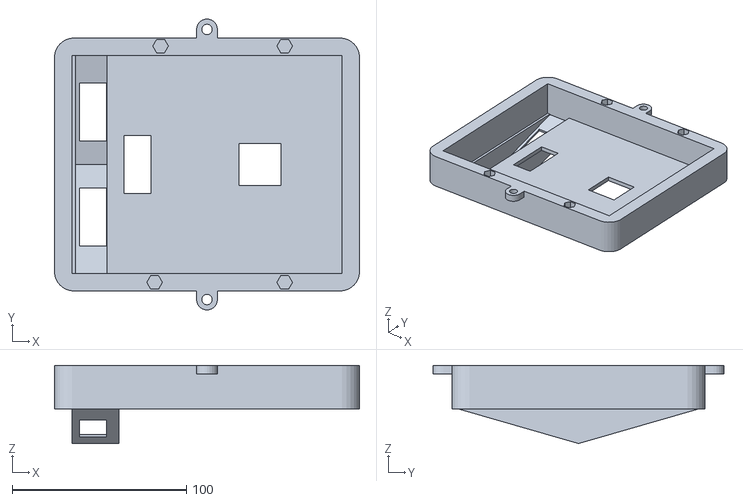
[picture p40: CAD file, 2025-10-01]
Hardware/Diseño3d/segundo modelo tapa.stl
175.0 x 167.0 x 44.8

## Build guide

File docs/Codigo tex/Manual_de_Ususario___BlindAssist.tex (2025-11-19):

\documentclass[12pt,a4paper]{article}
\usepackage[spanish]{babel}
\usepackage[utf8]{inputenc}
\usepackage{hyperref}
\usepackage{float}
\usepackage{geometry}
\usepackage{xcolor}
\usepackage{array}
\usepackage{longtable}
\usepackage{chngcntr}
\counterwithin{figure}{section}
\counterwithin{table}{section}
\usepackage{graphicx}
\usepackage{fancyhdr}
\usepackage{adjustbox}

\geometry{margin=2.5cm}

% Definimos el color de los meses y líneas
\definecolor{mescolor}{HTML}{024d50}
\definecolor{linecolor}{HTML}{024d50}
\definecolor{verdeagua}{HTML}{1B9E96}
\definecolor{verdeoscuro}{HTML}{002C2D}
\definecolor{verdemedio}{HTML}{004F4E}

% Cambiar color de secciones
\usepackage{titlesec}
\titleformat{\section}
{\color{mescolor}\normalfont\Large\bfseries}
{}{0pt}{}
\titlespacing*{\section}{0pt}{*2}{*1}

% Línea negra debajo de cada mes
\newcommand{\separador}{\vspace{0.5cm}\noindent\rule{\linewidth}{0.5pt}\vspace{0.5cm}}

% Cambiar color en el índice y tamaño más grande
\usepackage{tocloft}
\renewcommand{\cftsecfont}{\color{mescolor}\bfseries\Large}
\renewcommand{\cftsecpagefont}{\color{mescolor}\bfseries\Large}

% Configuración encabezado y pie de página con líneas de color y largo ajustable
\pagestyle{fancy}
\fancyhf{}
\fancyhead[L]{\textbf{Proyecto BlindAssist}}
\fancyhead[R]{} % Espacio vacío para que no haya logo
\fancyfoot[C]{\thepage}

% Línea de encabezado de color y largo personalizado
\renewcommand{\headrulewidth}{0.4pt}
\renewcommand{\footrulewidth}{0.4pt}

\renewcommand{\headrule}{%
\color{linecolor}\hrule width 1\linewidth height 0.4pt \vskip0pt}
\renewcommand{\footrule}{%
\color{linecolor}\hrule width \linewidth height 0.4pt \vskip0pt}

\begin{document}

\begin{titlepage}
    \begin{center}
    
    % --- Imagen centrada en la parte superior ---
    \vspace*{2cm}
    \\[2cm] % <-- cambia la ruta a tu imagen

    % --- Título principal ---
    {\Huge\bfseries Proyecto BlindAssist \\[0.5cm]}
    {\Large Manual de Usuario}\\[1.5cm]

    % --- Institución o facultad ---
    {\large Escuela de Educación Secundaria Técnica N°7 "Taller Regional Quilmes"}\\
    {\large 7°2 Aviónica}\\

    % --- Espacio para dejar limpio el resto de la hoja ---
    \vfill
    \end{center}
\end{titlepage}

% Índice con numeración desde aquí
\setcounter{page}{1}
\setcounter{tocdepth}{4} % muestra hasta paragraph en el índice
\setcounter{secnumdepth}{4}
\tableofcontents
\newpage

\begin{center}
    \textbf{ Este manual podrá leerse mediante bots de voz.}
\end{center}

\section{Introducción}

El presente manual tiene como objetivo brindar una guía clara y accesible sobre el uso, funcionamiento y mantenimiento del dispositivo \textbf{BlindAssist}.

El objetivo de este proyecto es mantener la integridad de las personas ciegas o con algún tipo de discapacidad visual en cualquier tipo de entorno urbano y darles un mayor nivel de conciencia en entornos mas cerrados. Para ello, desarrollamos un dispositivo que mediante reconocimiento por inteligencia artificial y la detección de objetos utilizando tecnología láser para avisar al usuario sobre un obstáculo en frente, por encima de la cadera, la presencia de alguna persona en un espacio cerrado y la cantidad de individuos que se encuentran en el mismo espacio, contando con alertas sonoras y vibratorias que no alteren su percepción y condición actual.Este dispositivo funcionara como una ayuda al bastón que utilizan en su día a día sin modificar su efectividad o tratar de reemplazar su función.

\subsection{Problemas a resolver}

\begin{itemize}
\item Obstáculos repentinos en la vía publica, pueden presentar dificultad a la hora de detectar postes, árboles y otros peligros inesperados que se encuentren por encima de su tren inferior (a partir de la cadera), siendo que la mayoría de las veces el rango que cubre el bastón no es suficiente para detectar y avisar efectivamente a la persona con discapacidad visual.
\item El riesgo constante que sufren en la vía publica termina llevando a que dependan mucho de terceros, como puede ser transeúntes que los apoyen o en casos de personas con una edad mas avanzada, un cuidador designado o familiar cercano. Tenemos en cuenta la falta de autonomía que genera esta problemática, la dependencia que terminan teniendo de terceros es una de las problemáticas más importantes a resolver y la idea es darles una herramienta de autonomía e integración.
\item Proteger su intimidad pudiendo detectar personas que están en el mismo espacio cerrado sin depender de que la persona avise de su llegada, también permitiéndoles conocer la ubicación de dichos individuos, dándole un mejor sentido y conciencia situacional.
\end{itemize}
% ===========================================================
\section{Descripción general del sistema}

\subsection{Componentes principales}
\begin{itemize}
    \item \textbf{Raspberry Pi 4}
    \item \textbf{Cámara HQ / V2}
    \item \textbf{3 Sensores LiDAR TFmini}
    \item \textbf{Auriculares o parlante}
    \item \textbf{2 Motores vibradores} 
    \item \textbf{4 Baterías 18650}
    \item \textbf{Carcasa impresa en 3D}
\end{itemize}

\begin{center}
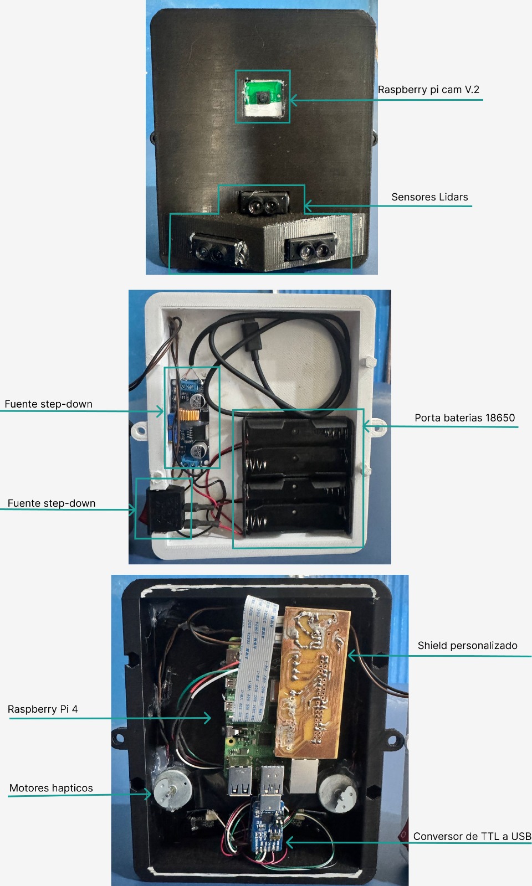
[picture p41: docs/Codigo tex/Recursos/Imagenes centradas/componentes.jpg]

\end{center}

\subsection{Funciones principales}
\begin{enumerate}
    \item Detección de elementos y análisis mediante IA.
    \item Emisión de alertas por voz simples para comunicar efectivamente elementos importantes.
    \item Detección de objetos intrusos con un rango de 120 grados frente al dispositivo mediante lasers colocados estratégicamente.
    \item Comunicación de objetos intrusos frente al usuario mediante motores a cada lado del dispositivo.
\end{enumerate}

% ===========================================================
\section{Instalación y encendido}

\subsection{Carga inicial}
\begin{enumerate}
    \item Abrir la carcasa del dispositivo.
    \item En caso de contar con baterías 18650 no recargables, conectar directamente.
    \item En caso de contar con baterías 18650 recargables, cargar completamente las baterías con el cargador inteligente de 18650.
    \item Conectar las baterías al porta baterías del dispositivo.
\end{enumerate}

\subsection{Encendido del sistema}
\begin{enumerate}
    \item Conectar auriculares de cable a la entrada de jack al lateral del dispositivo. (Cualquier tipo de auricular por cable, se recomiendan del tipo diadema.)
    \item Presionar el botón de encendido al lateral del dispositivo.
    \item Puede verificar su encendido viendo la luz led roja del botón o teniendo los auriculares ya conectados y puestos se escuchara un aviso de que BlindAssist ya esta funcionando.

\begin{center}

\end{center}
    
    \item Presionar botón de detección 1 para activar la detección de elementos por IA (Es recomendado hacerlo en una habitación con poco movimiento o cantidad de personas para evitar una saturación y mensajes erróneos o confusos). Volver a presionar el dispositivo para desactivar la detección de elementos por IA

\begin{center}
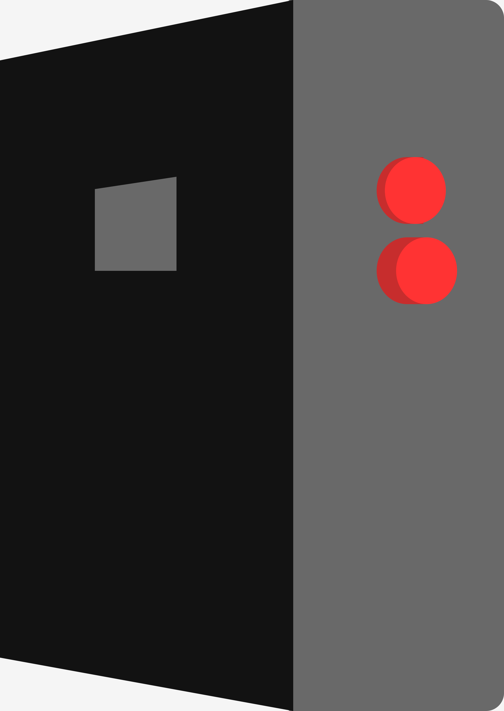
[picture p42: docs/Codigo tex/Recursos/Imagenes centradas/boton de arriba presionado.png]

\end{center}
    
    \item Presionar botón de detección 2 para activar la detección de elementos intrusos o irregulares frente al usuario.

\begin{center}
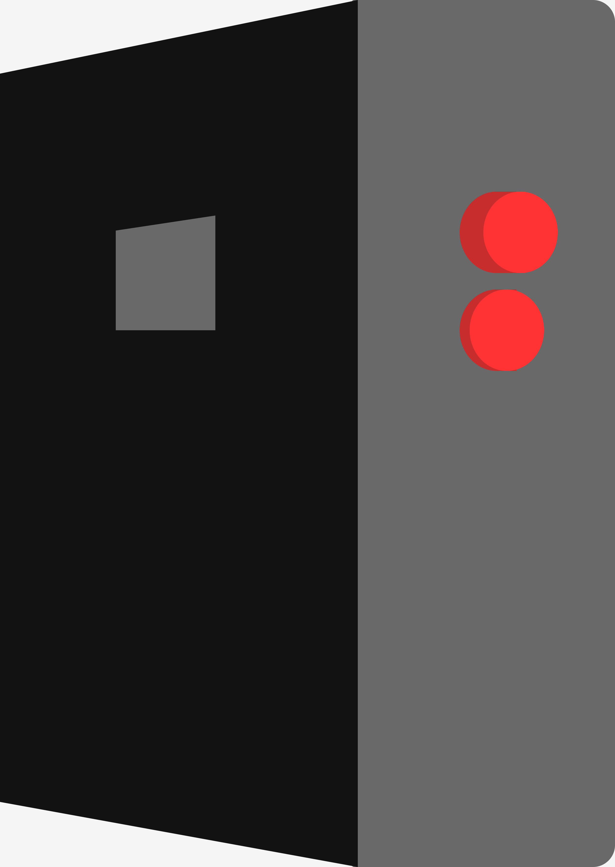
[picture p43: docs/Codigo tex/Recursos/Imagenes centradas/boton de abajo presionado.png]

\end{center}

\end{enumerate}

\subsection{Colocación}
El dispositivo puede sujetarse al pecho, cinturón o mochila mediante el sistema de acople, siempre orientado hacia adelante y sin obstrucciones en los sensores.

\begin{center}
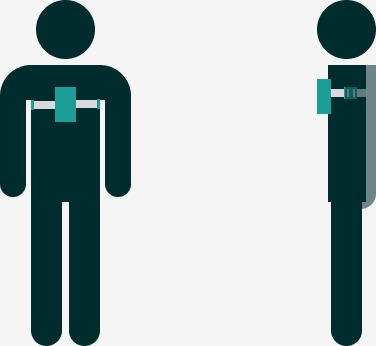
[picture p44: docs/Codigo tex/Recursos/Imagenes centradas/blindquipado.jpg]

\end{center}

% ===========================================================
\section{Uso del dispositivo}

\subsection{Modos de alerta}
\begin{itemize}
    \item \textbf{Vibración:} indica obstáculos cercanos.
    \item \textbf{Alerta de voz:} informa tipo de objeto o dirección.
\end{itemize}

\subsection{Interpretación de señales}

\subsubsection*{Caso 1 – Obstáculo en el lado derecho}
Cuando el sensor derecho detecta un objeto a corta distancia, el sistema reduce o ajusta la velocidad del motor derecho.

\begin{center}

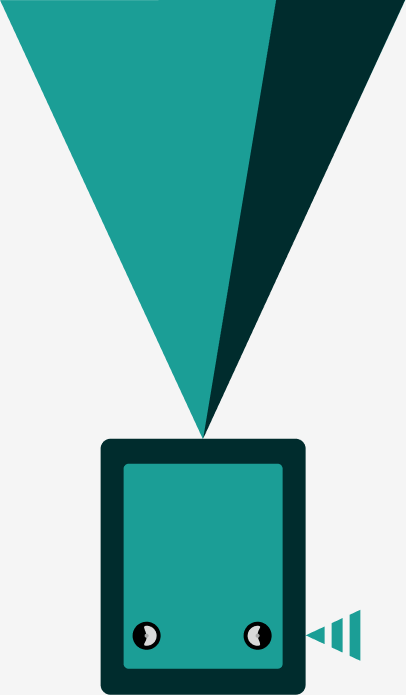
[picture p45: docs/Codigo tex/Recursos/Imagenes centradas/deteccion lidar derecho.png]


 \caption{Detección derecha y alerta. }

\end{center}

\subsubsection*{Caso 2 – Obstáculo en el lado izquierdo}
Si el sensor izquierdo detecta un objeto cercano, el sistema disminuye o ajusta la velocidad del motor izquierdo.  

\begin{center}

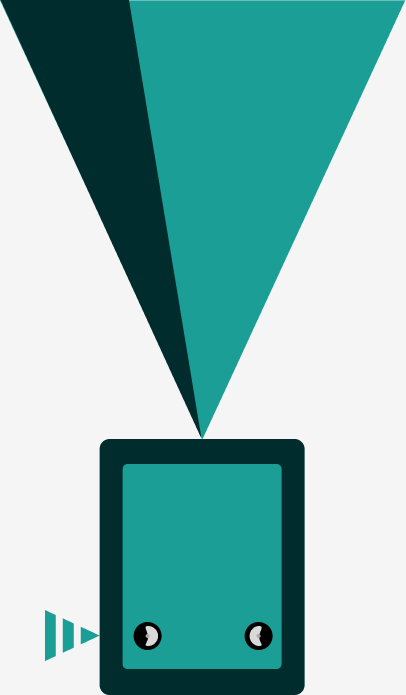
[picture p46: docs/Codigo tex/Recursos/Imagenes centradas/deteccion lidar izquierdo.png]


 \caption{Detección izquierda y alerta. }

\end{center}

\subsubsection*{Caso 3 – Obstáculo al frente}
Cuando el sensor frontal percibe un objeto demasiado cerca, ambos motores responden al mismo tiempo.

\begin{center}

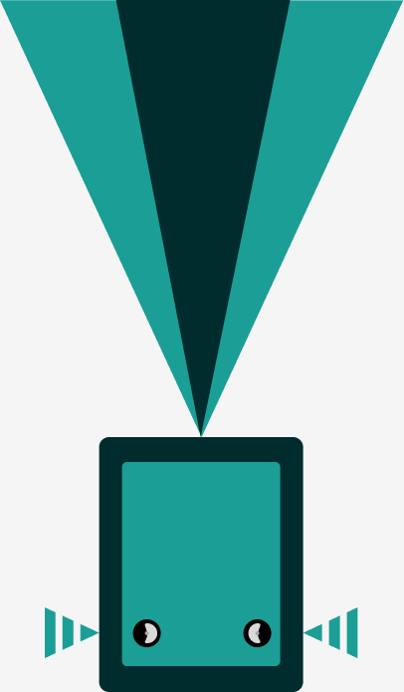
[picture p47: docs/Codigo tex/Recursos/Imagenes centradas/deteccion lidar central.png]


 \caption{Detección centro y alerta. }

\end{center}

\subsubsection*{Caso 4 – Obstáculo al frente y a la izquierda}
Si el sistema detecta objetos al frente y al lado izquierdo, el motor izquierdo comienza a funcionar de forma intermitente.  
Esto indica que el dispositivo intenta girar hacia la derecha o alerta de una zona con obstáculos muy próximos.

\begin{center}

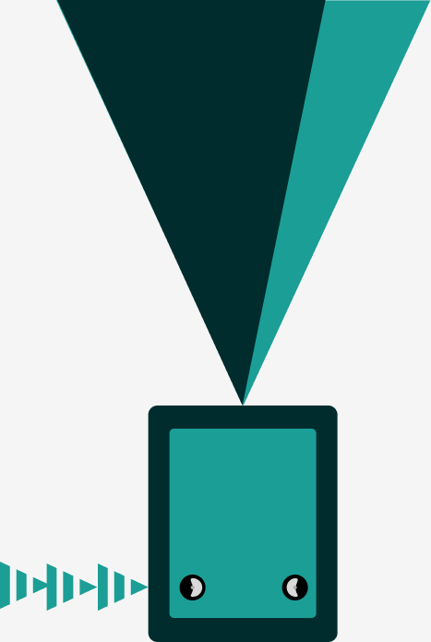
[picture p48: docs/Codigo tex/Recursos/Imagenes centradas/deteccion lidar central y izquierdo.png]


 \caption{Detección centro-izquierda y alerta. }

\end{center}

\subsubsection*{Caso 5 – Obstáculo al frente y a la derecha}
Cuando el dispositivo detecta obstáculos adelante y en el lado derecho, el motor derecho opera de manera intermitente.

\begin{center}

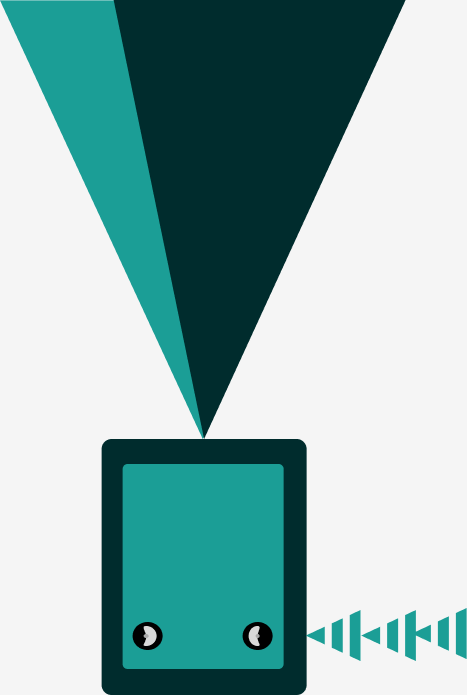
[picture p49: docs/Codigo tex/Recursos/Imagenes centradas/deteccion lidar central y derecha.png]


 \caption{Detección centro-derecha y alerta. }

\end{center}

\subsubsection*{Caso 6 – Obstáculos al frente, derecha e izquierda}
Si los tres sensores detectan objetos cercanos simultáneamente . En esta situación, ambos motores se activan al máximo indicando que está rodeado de obstáculos y no puede avanzar con seguridad.

\begin{center}

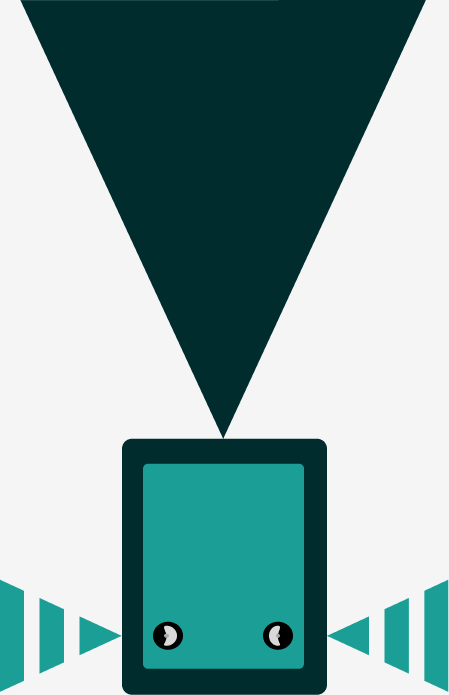
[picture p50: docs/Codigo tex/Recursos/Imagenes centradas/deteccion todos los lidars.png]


 \caption{Detección centro-izquierda-derecha y alerta. }

\end{center}

\subsubsection{Intensidad}
\item Dependiendo de la cercanía de los obstáculos, los motores variarán su intensidad de vibración para una alerta más precisa.

\begin{center}

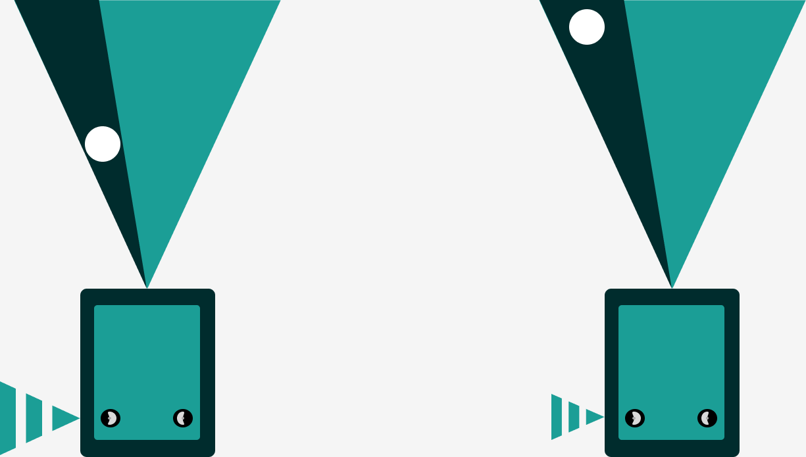
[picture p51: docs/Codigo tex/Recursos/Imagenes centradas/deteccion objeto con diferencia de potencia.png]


 \caption{Detección con variante de potencia. }

\end{center}

\subsubsection{Detección de personas/objetos.}
La cámara detectará personas y/o objetos, y alertará esto a través de la voz del dispositivo.
A continuación, algunos ejemplos:

\begin{center}

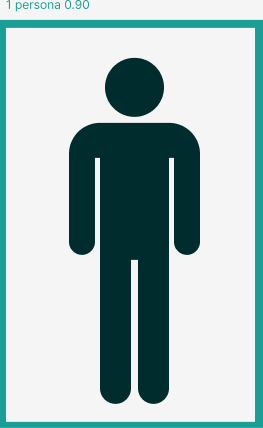
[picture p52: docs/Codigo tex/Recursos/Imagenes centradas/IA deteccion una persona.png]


 \caption{Detección único individuo.}

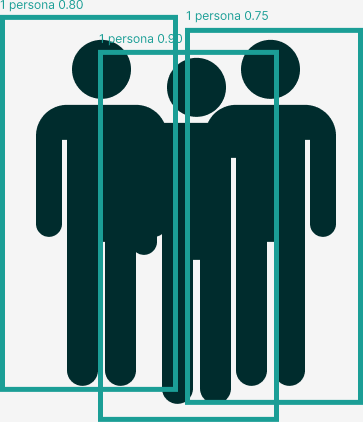
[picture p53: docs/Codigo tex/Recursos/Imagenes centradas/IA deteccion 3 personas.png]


 \caption{Detección varios individuos.}

\end{center}

\begin{center}

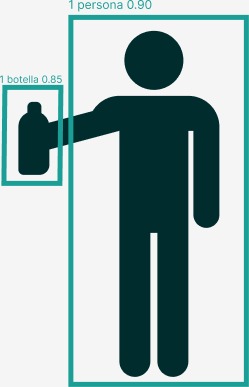
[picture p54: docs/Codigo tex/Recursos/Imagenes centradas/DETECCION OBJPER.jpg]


 \caption{Detección de un individuo y un objeto. }

\end{center}
% ===========================================================
\section{Mantenimiento}

\subsection{Limpieza}
\begin{itemize}
    \item Limpiar con paño seco o ligeramente húmedo.
    \item Evitar alcohol o líquidos corrosivos.
    \item No abrir la carcasa con el equipo encendido.
\end{itemize}

% ===========================================================
\section{Solución de problemas comunes}

\begin{table}[H]
\centering
\begin{tabular}{|c|p{5cm}|p{7cm}|}
\hline
\textbf{Problema} & \textbf{Causa posible} & \textbf{Solución} \\ \hline
No enciende & Baterías descargadas o mal conectadas & Revisar carga y polaridad \\ \hline
Sin sonido & Auriculares desconectados o volumen bajo & Conectar y ajustar volumen \\ \hline
Sin vibración & Motor desconectado & Revisar conexión interna \\ \hline
Vibraciones continuas & Sensor sucio u obstruido & Limpiar superficie del sensor \\ \hline
Mensajes erróneos & Cámara desalineada o exceso de luz & Reajustar posición \\ \hline
\end{tabular}
\end{table}

% ===========================================================
\section{Especificaciones técnicas}

\begin{table}[H]
\centering
\begin{tabular}{|>{\bfseries}l|l|}
\hline
Componente & Descripción \\ \hline
Procesador & Raspberry Pi 4 (8 GB RAM) \\ \hline
Sensores & 3 × TFmini LiDAR \\ \hline
Cámara & Raspberry Pi Camera V2 / HQ \\ \hline
Alimentación & 2 × Baterías 18650 (3.7 V) \\ \hline
Autonomía & 4-6 horas continuas \\ \hline
Sistema Operativo & Raspberry Pi OS con IA integrada \\ \hline
Peso total & 300 g aprox. \\ \hline
\end{tabular}
\end{table}

% ===========================================================
\section{Seguridad del usuario}

\begin{itemize}
    \item No usar bajo lluvia intensa sin protección.
    \item No apuntar la cámara directamente al sol.
    \item No manipular partes internas mientras el sistema esté encendido.
    \item Utilizar como complemento del bastón, no como sustituto.
    \item No sumergir.
\end{itemize}

% ===========================================================
\section{Contacto y soporte}

\begin{itemize}
    \item Mail de contacto: \href{blindassist2025@gmail.com}{blindassist2025@gmail.com}
    \item Teléfono de contacto: +54 9 11 5817-4858
    \item Instagram: \href{https://www.instagram.com/blindassist/}{https://www.instagram.com/blindassist/}
    \item Página Web: \href{https://castiilloramiro.github.io/BlindWeb/}{https://castiilloramiro.github.io/BlindWeb/}
\end{itemize}

\subsection*{Registro de trabajo}
    \begin{itemize}
        \item trello: \href{https://trello.com/b/UIw0bKgf/kanban}{https://trello.com/b/UIw0bKgf/kanban}
        \item github: \href{https://github.com/impatrq/BLINDSSIST}{https://github.com/impatrq/BLINDSSIST}
    \end{itemize}

\textbf{Proyecto BlindAssist}\\
\textbf{Escuela de Educación Secundaria Tecnica N°7 "Taller Regional Quilmes"}\\
\textbf{7° 2° Aviónica}\\

Versión del manual: 1.0 – 2025

\end{document}

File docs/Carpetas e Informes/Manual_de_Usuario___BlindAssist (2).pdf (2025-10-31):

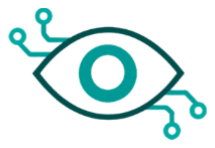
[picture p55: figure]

# Proyecto BlindAssist

## Manual de Usuario

### Escuela de Educación Secundaria Técnica N°7 ”Taller Regional Quilmes 7°2 Aviónica

## Índice

1 Introducción | 2
2 Descripción general del sistema | 2
3 Instalación y encendido | 3
4 Uso del dispositivo | 4
5 Mantenimiento | 7
6 Solución de problemas comunes | 7
7 Especificaciones técnicas | 8
8 Seguridad del usuario | 8
9 Contacto y soporte | 8

Proyecto BlindAssist

Este manual podrá leerse mediante bots de voz.

## Introducción

El presente manual tiene como objetivo brindar una guía clara y accesible sobre el uso, funcionamiento y mantenimiento del dispositivo BlindAssist.
El objetivo de este proyecto es mantener la integridad de las personas ciegas o con algún tipo de discapacidad visual en cualquier tipo de entorno urbano y darles un mayor nivel de conciencia en entornos mas cerrados. Para ello, desarrollamos un dispositivo que mediante reconocimiento por inteligencia artificial y la detección de objetos utilizando tecnología láser para avisar al usuario sobre un obstáculo en frente, por encima de la cadera, la presencia de alguna persona en un espacio cerrado y la cantidad de individuos que se encuentran en el mismo espacio, contando con alertas sonoras y vibratorias que no alteren su percepción y condición actual.Este dispositivo funcionara como una ayuda al bastón que utilizan en su día a día sin modificar su efectividad o tratar de reemplazar su función.

### 1.1. Problemas a resolver

Obstáculos repentinos en la vía publica, pueden presentar dificultad a la hora de detectar postes, árboles y otros peligros inesperados que se encuentren por encima de su tren inferior (a partir de la cadera), siendo que la mayoría de las veces el rango que cubre el bastón no es suficiente para detectar y avisar efectivamente a la persona con discapacidad visual.

El riesgo constante que sufren en la vía publica termina llevando a que dependan mucho de terceros, como puede ser transeúntes que los apoyen o en casos de personas con una edad mas avanzada, un cuidador designado o familiar cercano. Tenemos en cuenta la falta de autonomía que genera esta problemática, la dependencia que terminan teniendo de terceros es una de las problemáticas más importantes a resolver y la idea es darles una herramienta de autonomía e integración.

Proteger su intimidad pudiendo detectar personas que están en el mismo espacio cerrado sin depender de que la persona avise de su llegada, también permitiéndoles conocer la ubicación de dichos individuos, dándole un mejor sentido y conciencia situacional.

## Descripción general del sistema

### 2.1. Componentes principales

Raspberry Pi 4

Cámara HQ / V2

### 3 Sensores LiDAR TFmini

Auriculares o parlante

### 2 Motores vibradores

### 4 Baterías 18650

Carcasa impresa en 3D

### 2.2. Funciones principales

1. Detección de elementos y análisis mediante IA.
2. Emisión de alertas por voz simples para comunicar efectivamente elementos importantes.
3. Detección de objetos intrusos con un rango de 120 grados frente al dispositivo mediante lasers colocados estratégicamente.
4. Comunicación de objetos intrusos frente al usuario mediante motores a cada lado del dispositivo.

## Instalación y encendido

### 3.1. Carga inicial

1. Abrir la carcasa del dispositivo.
2. En caso de contar con baterías 18650 no recargables, conectar directamente.
3. En caso de contar con baterías 18650 recargables, cargar completamente las baterías con el cargador inteligente de 18650.
4. Conectar las baterías al porta baterías del dispositivo.

### 3.2. Encendido del sistema

1. Conectar auriculares de cable a la entrada de jack al lateral del dispositivo. (Cualquier tipo de auricular por cable, se recomiendan del tipo diadema.)
2. Presionar el botón de encendido al lateral del dispositivo.
3. Puede verificar su encendido viendo la luz led roja del botón o teniendo los auriculares ya conectados y puestos se escuchara un aviso de que BlindAssist ya esta funcionando.
4. Presionar botón de detección 1 para activar la detección de elementos por IA (Es recomendado hacerlo en una habitación con poco movimiento o cantidad de personas para evitar una saturación y mensajes erróneos o confusos). Volver a presionar el dispositivo para desactivar la detección de elementos por IA

5. Presionar botón de detección 2 para activar la detección de elementos intrusos o irregulares frente al usuario.

### 3.3. Colocación

El dispositivo puede sujetarse al pecho, cinturón o mochila mediante el sistema de acople, siempre orientado hacia adelante y sin obstrucciones en los sensores.

## Uso del dispositivo

### 4.1. Modos de alerta

Vibración: indica obstáculos cercanos.

Alerta de voz: informa tipo de objeto o dirección.

### 4.2. Interpretación de señales

Caso 1 – Obstáculo en el lado derecho

Cuando el sensor derecho detecta un objeto a corta distancia, el sistema reduce o ajusta la velocidad del motor derecho.

Recursos/deteccion lidar derecho.png

Detección derecha y alerta.

Caso 2 – Obstáculo en el lado izquierdo

Si el sensor izquierdo detecta un objeto cercano, el sistema disminuye o ajusta la velocidad del motor izquierdo.

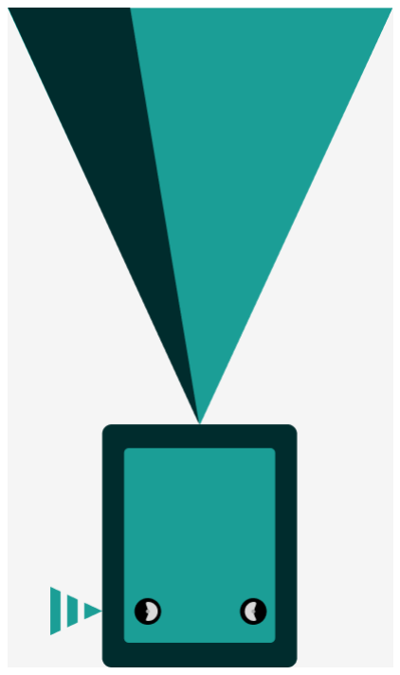
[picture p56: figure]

Detección izquierda y alerta.

Caso 3 – Obstáculo al frente

Cuando el sensor frontal percibe un objeto demasiado cerca, ambos motores responden al mismo tiempo.

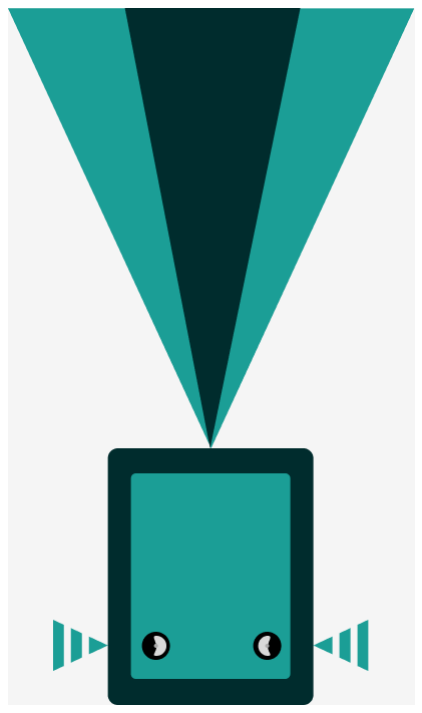
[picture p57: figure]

Detección centro y alerta.

Caso 4 – Obstáculo al frente y a la izquierda

Si el sistema detecta objetos al frente y al lado izquierdo, el motor izquierdo comienza a funcionar de forma intermitente. Esto indica que el dispositivo intenta girar hacia la derecha o alerta de una zona con obstáculos muy próximos.

Detección centro-izquierda y alerta.

Caso 5 – Obstáculo al frente y a la derecha

Cuando el dispositivo detecta obstáculos adelante y en el lado derecho, el motor derecho opera de manera intermitente.

Detección centro-derecha y alerta.

Caso 6 – Obstáculos al frente, derecha e izquierda

Si los tres sensores detectan objetos cercanos simultáneamente . En esta situación, ambos motores se activan al máximo indicando que está rodeado de obstáculos y no puede avanzar con seguridad.

Detección centro-izquierda-derecha y alerta.

### 4.2.1. Intensidad

Dependiendo de la cercanía de los obstáculos, los motores variarán su intensidad de vibración para una alerta más precisa.

Detección con variante de potencia.

4.2.2. Detección de personas/objetos.

La cámara detectará personas y/o objetos, y alertará esto a través de la voz del dispositivo. A continuación, algunos ejemplos:

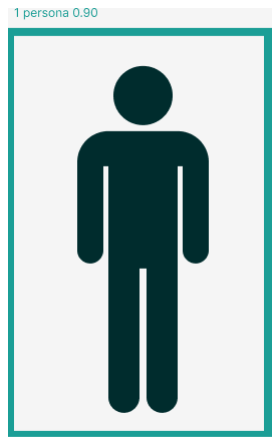
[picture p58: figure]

Detección único individuo.

Detección varios individuos.

Detección de un individuo y un objeto.

## Mantenimiento

### 5.1. Limpieza

Limpiar con paño seco o ligeramente húmedo.

Evitar alcohol o líquidos corrosivos.

No abrir la carcasa con el equipo encendido.

## Solución de problemas comunes

Problema | Causa posible | Solución
No enciende | Baterías descargadas o mal conectadas | Revisar carga y polaridad
Sin sonido | Auriculares desconectados o volumen bajo | Conectar y ajustar volumen
Sin vibración | Motor desconectado | Revisar conexión interna
Vibraciones continuas | Sensor sucio u obstruido | Limpiar superficie del sensor
Mensajes erróneos | Cámara desalineada o exce-so de luz | Reajustar posición

## Especificaciones técnicas

Componente | Descripción
Procesador | Raspberry Pi 4 (8 GB RAM)
Sensores | 3 × TFmini LiDAR
Cámara | Raspberry Pi Camera V2 / HQ
Alimentación | 2 × Baterías 18650 (3.7 V)
Autonomía | 4-6 horas continuas
Sistema Operativo | Raspberry Pi OS con IA integrada
Peso total | 300 g aprox.

## Seguridad del usuario

No usar bajo lluvia intensa sin protección.

No apuntar la cámara directamente al sol.

No manipular partes internas mientras el sistema esté encendido.

Utilizar como complemento del bastón, no como sustituto.

No sumergir.

## Contacto y soporte

Mail de contacto: blindassist2025@gmail.com

Teléfono de contacto: +54 9 11 5817-4858

Instagram: https://www.instagram.com/blindassist/

Página Web: https://castiilloramiro.github.io/BlindWeb/

### Registro de trabajo

trello: https://trello.com/b/UIw0bKgf/kanban

github: https://github.com/impatrq/BLINDSSIST

Proyecto BlindAssist
Escuela de Educación Secundaria Tecnica N°7 ”Taller Regional Quilmes” 7° 2° Aviónica

Versión del manual: 1.0 – 2025

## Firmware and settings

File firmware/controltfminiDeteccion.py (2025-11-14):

import time
import threading
import RPi.GPIO as GPIO
import subprocess
import sys
import os
import cv2
from picamera2 import Picamera2
from ultralytics import YOLO

# Módulo para sensores TFmini3 y diccionario compartido 'distancias'
try:
    from TFmini3 import distancias, getTFminiData_uart1, getTFminiData_uart2, getTFminiData_uart3
except ImportError:
    # Simula valores de distancia y funciones si la importación falla
    distancias = {"uart1": 200, "uart2": 200, "uart3": 200}
    def getTFminiData_uart1(): time.sleep(1)
    def getTFminiData_uart2(): time.sleep(1)
    def getTFminiData_uart3(): time.sleep(1)


# Configuración de pines de hardware para motores
MOTOR_PIN1 = 12     # PWM 1
MOTOR_PIN2 = 13     # PWM 2

BUTTON_HAPTIC_PIN = 8    # Botón para activar/desactivar control háptico
BUTTON_VISUAL_PIN = 25   # Botón para activar/desactivar detección visual

GPIO.setmode(GPIO.BCM)
GPIO.setup(MOTOR_PIN1, GPIO.OUT)
GPIO.setup(MOTOR_PIN2, GPIO.OUT)
GPIO.setup(BUTTON_HAPTIC_PIN, GPIO.IN, pull_up_down=GPIO.PUD_UP)
GPIO.setup(BUTTON_VISUAL_PIN, GPIO.IN, pull_up_down=GPIO.PUD_UP)

# Inicialización de PWM
pwm1 = GPIO.PWM(MOTOR_PIN1, 100)
pwm2 = GPIO.PWM(MOTOR_PIN2, 100)
pwm1.start(0)
pwm2.start(0)


estado_haptico_activo = False
estado_visual_activo = False


# ====================================================================
# NUEVAS FUNCIONES DE CALLBACK
# ====================================================================

def toggle_haptico(channel):
    """Invierte el estado del control háptico al presionar el botón."""
    global estado_haptico_activo
    estado_haptico_activo = not estado_haptico_activo
    print(f"DEBUG: Haptico activo: {estado_haptico_activo}") # Opcional: para verificar

def toggle_visual(channel):
    """Invierte el estado de la detección visual al presionar el botón."""
    global estado_visual_activo
    estado_visual_activo = not estado_visual_activo
    print(f"DEBUG: Visual activo: {estado_visual_activo}") # Opcional: para verificar

# ====================================================================
# LÓGICA DE CONTROL HÁPTICO (LiDAR)
# Control coordinado de PWM basado en la proximidad de los 3 sensores.
# ====================================================================

def calcular_duty(d):
    """Convierte la distancia (cm) a ciclo de trabajo (duty cycle) de 0% a 100%."""
    if d is None or d >= 120:
        return 0
    return min(100, 120 - d)

def control_sensores():
    """Ejecuta el bucle principal que aplica el PWM a los motores según las reglas de proximidad."""
    global estado_haptico_activo
    toggle1 = False
    toggle2 = False
    
    while True:
        # 1. INICIALIZACIÓN: Los motores se apagan por defecto
        # Asume que no hay peligro. Se sobreescribirá si se detecta proximidad.
        pwm1.ChangeDutyCycle(0)
        pwm2.ChangeDutyCycle(0)

        # Si el modo háptico está desactivado, salta la lógica
        if not estado_haptico_activo:
            time.sleep(0.1)
            continue
        
        # Bandera para saber si se ha detectado peligro
        peligro_detectado = False 

        d1 = distancias.get("uart1")
        d2 = distancias.get("uart2")
        d3 = distancias.get("uart3")

        duty1 = calcular_duty(d1)
        duty2 = calcular_duty(d2)
        duty3 = calcular_duty(d3)
        
        # =========================================================
        # REGLAS DE PROXIMIDAD (De la más restrictiva a la menos)
        # =========================================================

        # 1. CASO 6: LOS TRES < 120 (Máxima alerta)
        if all(d is not None and d < 120 for d in [d1, d2, d3]):
            pwm1.ChangeDutyCycle(100)
            pwm2.ChangeDutyCycle(100)
            peligro_detectado = True
            # No uses continue aquí, usa else if para que un caso no anule a los demás.
        
        # 2. CASO 4: UART2 y UART3 <120 (Titila Motor 2)
        elif (d2 is not None and d2 < 120) and (d3 is not None and d3 < 120):
            toggle2 = not toggle2
            pwm2.ChangeDutyCycle(duty2 if toggle2 else 0)
            pwm1.ChangeDutyCycle(0) # Asegura el estado del otro motor
            time.sleep(0.3) # Mantén el sleep para el efecto de titileo
            peligro_detectado = True
        
        # 3. CASO 5: UART1 y UART3 <120 (Titila Motor 1)
        elif (d1 is not None and d1 < 120) and (d3 is not None and d3 < 120):
            toggle1 = not toggle1
            pwm1.ChangeDutyCycle(duty1 if toggle1 else 0)
            pwm2.ChangeDutyCycle(0) # Asegura el estado del otro motor
            time.sleep(0.3) # Mantén el sleep para el efecto de titileo
            peligro_detectado = True

        # 4. CASO 3: SOLO UART3 <120 (Ambos motores iguales)
        elif d3 is not None and d3 < 120:
            pwm1.ChangeDutyCycle(duty3)
            pwm2.ChangeDutyCycle(duty3)
            peligro_detectado = True
            
        # 5. CASOS 1 y 2: Comportamiento individual (si no se cumplen los casos anteriores)
        else: 
            if d1 is not None and d1 < 120:
                pwm1.ChangeDutyCycle(duty1)
                peligro_detectado = True
                
            if d2 is not None and d2 < 120:
                pwm2.ChangeDutyCycle(duty2)
                peligro_detectado = True
        
        # **ELIMINA TODOS LOS `continue` DENTRO DE LOS BLOQUES `if`**

        # Retraso normal del bucle. Usamos 0.1s o el tiempo del titileo
        if not peligro_detectado:
              time.sleep(0.1)

# ====================================================================
# MÓDULOS DE DETECCIÓN VISUAL (Clases)
# ====================================================================

class Camara:
    """Gestiona la captura de frames de video de la Picamera2."""
    def __init__(self, width=640, height=480):
        self.__width = width
        self.__height = height
        self.__picam2 = None

    def iniciar(self):
        """Inicia el stream de la cámara."""
        try:
            self.__picam2 = Picamera2()
            config = self.__picam2.create_preview_configuration(main={"size": (self.__width, self.__height)})
            self.__picam2.configure(config)
            self.__picam2.start()
            return True
        except Exception:
            return False

    def detener(self):
        """Detiene el stream."""
        if self.__picam2:
            self.__picam2.stop()

    def capturar_frame(self):
        """Captura un frame y lo convierte a formato BGR (OpenCV)."""
        if self.__picam2:
            frame = self.__picam2.capture_array()
            return cv2.cvtColor(frame, cv2.COLOR_RGB2BGR)
        return None

class Voz:
    """Maneja la síntesis de voz (espeak) de forma asíncrona para evitar bloquear la IA."""
    def __init__(self, velocidad=150):
        self.__velocidad = velocidad

    def hablar(self, texto):
        """Pronuncia el texto en un hilo separado."""
        try:
            command = ['espeak', f'-s {self.__velocidad}', f'"{texto}"', '-v', 'es']
            threading.Thread(target=lambda: subprocess.run(command, check=True), daemon=True).start()
        except Exception:
            pass # Ignora fallos si espeak no está disponible o falla

class Traductor:
    """Proporciona traducciones de nombres de objetos de YOLO (inglés a español)."""
    def __init__(self):
        self.__traducciones = {
            'person': 'persona', 'car': 'auto', 'bicycle': 'bicicleta', 'motorcycle': 'moto',
            'bus': 'colectivo', 'truck': 'camión', 'cell phone': 'celular', 'bottle': 'botella',
            'tv': 'televisor'
        }

    def traducir(self, palabra_ingles):
        """Traduce una palabra."""
        return self.__traducciones.get(palabra_ingles, palabra_ingles)
        
    def obtener_clases_permitidas(self):
        """Devuelve la lista de clases conocidas para el filtro de YOLO."""
        return list(self.__traducciones.keys())

class IA:
    """Carga y ejecuta el modelo YOLOv8 para la detección de objetos."""
    def __init__(self, model_path, confidence_threshold, allowed_classes):
        if not os.path.exists(model_path):
            sys.exit(1)
        try:
            self.__model = YOLO(model_path)
            self.__confidence_threshold = confidence_threshold
            self.__allowed_classes = allowed_classes
        except Exception:
            sys.exit(1)
            
    def analizar_imagen(self, frame):
        """Procesa un frame, filtra las detecciones por confianza y clase, y cuenta objetos."""
        results = self.__model(frame, verbose=False)[0]
        objetos_detectados = {}
        for box in results.boxes:
            class_id = int(box.cls[0])
            class_name = self.__model.names[class_id]
            confidence = float(box.conf[0])
            if class_name in self.__allowed_classes and confidence > self.__confidence_threshold:
                objetos_detectados[class_name] = objetos_detectados.get(class_name, 0) + 1
        return objetos_detectados

class AsistentePrincipal:
    """Orquesta la detección visual, la IA, la traducción y la voz."""
    def __init__(self):
        self.__traductor = Traductor()
        self.__voz = Voz()
        self.__camara = Camara()
        self.__ia = IA(
            model_path="yolov8n.pt", 
            confidence_threshold=0.6, 
            allowed_classes=self.__traductor.obtener_clases_permitidas()
        )
        self.__last_detected_objects = {}

    def __anunciar_detecciones(self, objetos_actuales):
        """Compara detecciones con el estado anterior y genera anuncios de voz concisos."""
        anuncios = []
        
        # Anuncia objetos nuevos o cambios de cantidad
        for class_name, count in objetos_actuales.items():
            last_count = self.__last_detected_objects.get(class_name, 0)
            if count != last_count:
                spanish_name = self.__traductor.traducir(class_name)
                message = f"{count} {spanish_name}." if count > 1 else f"Una {spanish_name}."
                anuncios.append(message)
        
        # Anuncia objetos que desaparecieron
        for class_name, last_count in self.__last_detected_objects.items():
            if class_name not in objetos_actuales and last_count > 0:
                spanish_name = self.__traductor.traducir(class_name)
                message = f"{spanish_name} fuera."
                anuncios.append(message)

        if anuncios:
            final_message = " ".join(anuncios) 
            self.__voz.hablar(final_message)
            
        self.__last_detected_objects = objetos_actuales.copy()

    def iniciar_visual_loop(self):
        """Ejecuta el bucle principal de captura, análisis de IA y anuncio."""
        global estado_visual_activo
        if not self.__camara.iniciar():
            return

        self.__voz.hablar("Asistente combinado iniciado.")
        
        try:
            while True:
                if not estado_visual_activo:
                    time.sleep(0.1)
                    continue

                frame = self.__camara.capturar_frame()
                if frame is None:
                    time.sleep(1)
                    continue
                
                objetos_actuales = self.__ia.analizar_imagen(frame)
                self.__anunciar_detecciones(objetos_actuales)
                
                time.sleep(0.1) 

        except (KeyboardInterrupt, SystemExit):
            pass
        except Exception:
            pass
            
        finally:
            self.__camara.detener()


# ====================================================================
# FUNCIÓN PRINCIPAL (MAIN)
# ====================================================================

def main():
    """Configura e inicia los hilos para el sistema háptico y visual simultáneamente."""
    
    asistente = AsistentePrincipal()
    
    try:
        # Inicia hilos para la lectura de los 3 LiDARs (UART)
        threading.Thread(target=getTFminiData_uart1, daemon=True).start()
        threading.Thread(target=getTFminiData_uart2, daemon=True).start()
        threading.Thread(target=getTFminiData_uart3, daemon=True).start()

        # Gestiona los botones físicos con resistencia pull-up interna
        GPIO.add_event_detect(
            BUTTON_HAPTIC_PIN, 
            GPIO.FALLING, 
            callback=toggle_haptico, 
            bouncetime=300
        )
        GPIO.add_event_detect(
            BUTTON_VISUAL_PIN, 
            GPIO.FALLING, 
            callback=toggle_visual, 
            bouncetime=300
        )

        # Inicia el hilo centralizado para el control de PWM (háptico)
        threading.Thread(target=control_sensores, daemon=True).start()
        
        # Inicia el hilo principal de detección visual (cámara e IA)
        threading.Thread(target=asistente.iniciar_visual_loop, daemon=True).start()

        # El programa principal se mantiene activo
        while True:
            time.sleep(1)

    except KeyboardInterrupt:
        pass
        
    finally:
        # Limpieza de hardware al finalizar
        pwm1.stop()
        pwm2.stop()
        GPIO.cleanup()


if __name__ == "__main__":
    main()

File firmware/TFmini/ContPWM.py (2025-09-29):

import time
import threading
import RPi.GPIO as GPIO
from TFmini3 import distancias, getTFminiData_uart1, getTFminiData_uart2, getTFminiData_uart3  # importamos lo que ya hiciste

# Pines PWM (hardware soportados en RPi4: GPIO18 y GPIO13)
MOTOR_PIN1 = 18   # PWM 1
MOTOR_PIN2 = 13   # PWM 2

GPIO.setmode(GPIO.BCM)
GPIO.setup(MOTOR_PIN1, GPIO.OUT)
GPIO.setup(MOTOR_PIN2, GPIO.OUT)

# PWM iniciales: 100 Hz, duty cycle en 0% (motores inactivos al inicio)
pwm1 = GPIO.PWM(MOTOR_PIN1, 100)
pwm2 = GPIO.PWM(MOTOR_PIN2, 100)

pwm1.start(0)
pwm2.start(0)

# ---------------- FUNCIONES DE CONTROL ----------------

def control_motor_uart1():
    """Control del motor basado en la lectura UART1"""
    while True:
        d = distancias["uart1"]
        if d is not None:
            if d < 120:  # nueva distancia mínima
                duty = min(100, (120 - d))  # aumenta duty cuanto más cerca
            else:
                duty = 0  # motor inactivo
            pwm1.ChangeDutyCycle(duty)
            print(f"[UART1] Distancia: {d} cm | Duty PWM1: {duty}%")
        time.sleep(0.1)


def control_motor_uart2():
    """Control del motor basado en la lectura UART2"""
    while True:
        d = distancias["uart2"]
        if d is not None:
            if d < 120:
                duty = min(100, (120 - d))
            else:
                duty = 0
            pwm2.ChangeDutyCycle(duty)
            print(f"[UART2] Distancia: {d} cm | Duty PWM2: {duty}%")
        time.sleep(0.1)


def control_motor_uart3():
    """PWM intercalado entre ambos motores si la distancia < 120 cm"""
    toggle = True
    while True:
        d = distancias["uart3"]
        if d is not None:
            if d < 120:
                if toggle:
                    pwm1.ChangeDutyCycle(80)
                    pwm2.ChangeDutyCycle(0)
                else:
                    pwm1.ChangeDutyCycle(0)
                    pwm2.ChangeDutyCycle(80)
                toggle = not toggle
                print(f"[UART3] Distancia: {d} cm | PWM intercalado")
            else:
                # ambos motores inactivos si la distancia >= 120
                pwm1.ChangeDutyCycle(0)
                pwm2.ChangeDutyCycle(0)
        time.sleep(0.3)  # velocidad del parpadeo/intercalado

# ---------------- MAIN ----------------

if __name__ == "__main__":
    try:
        # hilos de lectura UART
        t1 = threading.Thread(target=getTFminiData_uart1, daemon=True)
        t2 = threading.Thread(target=getTFminiData_uart2, daemon=True)
        t3 = threading.Thread(target=getTFminiData_uart3, daemon=True)

        t1.start()
        t2.start()
        t3.start()

        # hilos de control PWM
        c1 = threading.Thread(target=control_motor_uart1, daemon=True)
        c2 = threading.Thread(target=control_motor_uart2, daemon=True)
        c3 = threading.Thread(target=control_motor_uart3, daemon=True)

        c1.start()
        c2.start()
        c3.start()

        # mantener el programa vivo
        while True:
            time.sleep(1)

    except KeyboardInterrupt:
        print("Cerrando programa...")
    finally:
        pwm1.stop()
        pwm2.stop()
        GPIO.cleanup()

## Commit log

2025-07-10 feat: agregar uart por software
2025-07-11 feat: versión python 3 de TF mini
2025-07-13 feat: guardar valores de distancia y fuerza
2025-07-13 feat: agregar configuración inical de pwm
2025-07-13 feat: implementación de lectura TFmini y configuración final
2025-09-02 feat:"correcciones de acotaciones"
2025-09-02 feat:"traspaso del codigo de POO"
2025-09-02 feat:"arrepentimiento, mejor subo el archivo"
2025-09-02 feat:"agrego el archivo con POO"
2025-09-02 feat:"detectar idomas motor de voz"
2025-09-03 feat: "Arreglar funcion GetTFminiData"
    [TFtest3.py]
2025-09-03 feat: "quitar prints de prueba"
2025-09-03 feat: "arreglar print"
2025-09-03 feat:" nuevo test y acambio de acotaciones"
2025-09-03 feat: "posible correccion de codigo"
2025-09-09 feat: "codigo de prueba funcional"
2025-09-09 feat:"codigo adaptado a la prueba funcional"
2025-09-10 test de la camara por csi
2025-09-10 Se completaron las pruebas de la cámara y el audio.
2025-09-10 feat: codigo de prueba deteccion de objetos (personas)
2025-09-10 feat:"Corregir el codigo a la ultima version del kernell"
2025-09-13 feat: "actualizar el codigo para el uso de 3 UART"
2025-09-14 feat: "Hacer test para funcionamiento de PWM"
2025-09-19 feat:Se probo y se implementó la lógica POO.
2025-09-19 feat:"agregar tercer uart"
2025-09-26 cambios de variables dentro de TFmini
2025-09-29 feat: Forzar Byte de lectura y actualizacion de PWM
2025-10-01 feat: cambio de variables tfmini
2025-10-01 feat: Diseños 3d primer y segundo prototipo
    [primer modelo1.stl, primermodelo2.stl, segundo modelo tapa.stl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]
2025-10-01 feat:intento de probar ambos codigos a la vez junto uso de botones
2025-10-03 feat quitamos los codigos que generarban problemas
    [controltfminiDeteccion.py]
2025-10-05 Create Carpeta_tecnica.tex
    feat:"subida de codigo de carpeta tecnica"
2025-10-06 Update README.md
    feat:"Corregir imagen de logo"
2025-10-06 Update README.md
    feat:"cambiar tamaño de la imagen"
2025-10-06 Update README.md
    feat:"cambiar tamaño de la imagen 2"
2025-10-06 feat:"Crear carpeta de Conversor UART"
2025-10-06 feat:"crear carpeta de fuente de alimentación"
2025-10-06 feat: Reorganizaciòn de logica de motores
2025-10-12 feat: Crear carpeta de imagenes de carpeta tecnica"
2025-10-13 Ultimas correcciones de los codigos
2025-10-14 feat: Borrar version antigua de carpeta de campo
2025-10-14 feat: codigo tex de carpeta de campo
2025-10-14 feat: Imagenes carpeta de campo
2025-10-14 feat: Subida de archivos falttantes
2025-10-15 feat: Subir carpeta de campo 2
2025-10-29 feat " agregar banner oficial"
    Banner utilizado para la presentación del proyecto, y utilizado en oniet
2025-10-31 feat: intercambio de docs
2025-10-31 feat: NUEVO manual de usuario
2025-10-31 feat: Delete docs/Recursos de video/vacio
2025-10-31 feat: Reestructuracion de readme provisional
    Updated the README.md to improve project description and formatting.
2025-10-31 feat: seguimos con el readme
2025-11-05 feat: ultimos modelos 3d
    [agarres.stl, tapafinal.stl]
2025-11-06 Create Ilustraciones del video
    Imagenes utilizadas para explicar el funcionamiento de blindassist en el video
2025-11-06 Tipos de detecciones
2025-11-10 feat: logo3d
    [BlindAssistLogo.stl]
2025-11-10 feat: nueva carpeta pcb
2025-11-10 feat: upload placas pcb
2025-11-12 Archivo de tareas inconclusas
2025-11-12 feat: Creacion de carpeta de curriculum
2025-11-12 feat: Subida de curriculum personal
2025-11-13 feat: README.md para hardware
    Added a README file to document hardware-related files and usage.
2025-11-13 se agrego la carpeta de tareas incolclusas
2025-11-13 feat: Implementar botones de selección
2025-11-13 feat: Cambio de variables
2025-11-13 feat: Arreglar rebote de motores
    [controltfminiDeteccion.py]
2025-11-13 feat: Arreglar logica de motores
    [controltfminiDeteccion.py]
2025-11-13 feat: Cambio de logica principal de boton
2025-11-14 Update controltfminiDeteccion.py
    Se agrego la funcion polling y se eliminaron ciertos eventos
2025-11-19 feat: Actualización final de carpeta de campo
2025-11-19 feat: Actualización de docs
    [Compras Blind Assist.xlsx, lista de componentes.xlsx]
